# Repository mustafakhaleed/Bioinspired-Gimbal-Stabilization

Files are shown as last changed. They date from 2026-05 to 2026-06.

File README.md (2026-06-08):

# Bioinspired Stabilizing System: 3-Axis Gimbal Control

This repository hosts the research, design, and implementation of a bioinspired 3-axis gimbal stabilizing system. The project integrates mechanical design (CAD), mathematical modeling (Lagrangian dynamics), and real-time control systems.

## 🚀 Overview
The system uses three **FB5311M digital servo motors** and an **MPU6050 IMU** to maintain precise orientation despite external disturbances. 

### Key Features:
* **3-Axis Control:** Independent stabilization for Yaw, Pitch, and Roll.
* **Bioinspired Design:** Structural optimization for 3D printing and component integration.
* **Dual Control Strategy:** Comparative analysis between Linear Quadratic Regulator (LQR) and Proportional-Integral-Derivative (PID) controllers.

## 📐 Mathematical Foundation
The system dynamics are modeled using the **Euler-Lagrange** method. 

### Lagrangian Mechanics:
The Lagrangian $L$ is defined as the difference between Kinetic Energy ($K$) and Potential Energy ($P$):
$$L = K - P$$

### State-Space Model:
For small-angle approximations, the system is represented as:
$$\dot{X} = AX + BU$$
$$Y = CX + DU$$

## 🕹️ Control Implementation
A significant finding in this project was the transition from **LQR** to **PID**. 
* **LQR:** While theoretically optimal, it struggled with the specific noise and dynamics introduced by the physical placement of the IMU.
* **PID:** Provided a more robust solution. Each axis was fine-tuned ($K_p$, $K_i$, $K_d$) to eliminate steady-state error and minimize overshoot.

## 🛠️ Tools Used
* **Hardware:** Arduino Uno, MPU6050 IMU, FB5311M Servos.
* **Software:** LabVIEW (Simulation & Logic Visualization), Arduino IDE (C++), SolidWorks/CAD (Modeling).
## 📺 Demo Video
You can watch the system in action here:
[Demo Video](https://drive.google.com/drive/folders/1tQpJcSNlK2p0POUrl_nZQ9yRdT6pHToe?hl=ar)

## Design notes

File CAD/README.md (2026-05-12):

# CAD Models
This folder contains the 3D design components for the Bioinspired Stabilizing System.

### Files:
* **STL Files:** Ready for 3D printing (Recommended: PLA or PETG, 20% Infill).
* **STEP Files:** Universal CAD format for editing in SolidWorks, Fusion 360, or AutoCAD.

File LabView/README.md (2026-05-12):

# LabVIEW Simulations & GUI
This folder contains the Virtual Instruments (VIs) used for system validation.

### Included Files:
* `Bioinspired Stabilizing System Dynamic Modeling and Control... .vi`: The main interface for real-time monitoring of gimbal angles.
* `Calibration uncontrolled .vi`: A utility for calibrating the IMU to eliminate gyroscopic drift and sensor offsets.

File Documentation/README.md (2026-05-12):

Contains the full project report, mathematical derivations, and high-resolution circuit diagrams.

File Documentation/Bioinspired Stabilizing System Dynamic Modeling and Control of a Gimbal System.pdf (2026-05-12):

## Bioinspired Stabilizing System: Dynamic Modeling and Control of a Gimbal System

Hamza Saleh (120210223), Mostafa Eissa (120210241), Abdelrahman Hisham (120210254), Abdelrahman Alamrawy (120210093), Mahmoud Moustafa Mahmoud (120210362)

Supervised by Prof. Ayman Nada

Abstract—This study investigates the design, dynamic modeling, and control of a bioinspired stabilizing system, with the aim of enhancing its accuracy and stability. The system is developed using 3D modeling software and consists of three FB5311M digital servo motors for 3-axis control (with feedback). A stable base is designed to house the MPU6050 sensor, Arduino microcontroller, and a battery to power the system. By developing a mathematical model, the relationship between the servo motor movements and the system’s orientation is established. Experimental validation is conducted to assess the system’s performance in maintaining precise orientation control. The results demonstrate the effectiveness of the developed model in achieving accurate and reliable operation of the bioinspired stabilizing system.
Keywords: Bioinspired Stabilizing System, Dynamic Modeling, Arduino UNO, LabVIEW
I. INTRODUCTION

The bioinspired stabilizing system under investigation serves as a critical tool in various applications, ranging from camera stabilization to educational robotics. Accurate orientation control and stability are essential for ensuring the efficient operation of such systems. In this study, we focus on the design, dynamic modeling, and control of a 3D-printed bioinspired stabilizing system utilizing three FB5311M digital servo motors for 3-axis control.
One of the primary challenges in developing a bioinspired stabilizing system is achieving precision and responsiveness in maintaining orientation. Variations in external conditions, such as sudden movements or vibrations, can affect system performance. To address these challenges, the proposed system incorporates an MPU6050 sensor for real-time orientation measurement and uses an Arduino microcontroller to process the sensor data and control the servo motors.
The bioinspired stabilizing system is designed and 3D-printed to ensure compatibility with its components, including the MPU6050 sensor, Arduino board, and power supply (Liion batteries). A mathematical model is developed to describe the dynamics of the system, and the Arduino-based control strategy is implemented to regulate servo movements based on the yaw, pitch, and roll angles.

Experimental validation of the proposed system is conducted to evaluate its performance in maintaining stable orientation. The results demonstrate the effectiveness of the developed model and control strategy in achieving precise and reliable operation. Additionally, the project offers an accessible and educational platform for learning about dynamic modeling, control systems, and 3D printing technologies.

II. SYSTEM ANALYSIS
The bioinspired stabilizing system consists of the following components:
- FB5311M Digital Servo Motors: Three digital servo motors provide 3-axis control (yaw, pitch, and roll) for precise orientation adjustments.
- MPU6050 Sensor: A 6-axis IMU sensor used to measure angular velocity and acceleration, providing real-time orientation data.
- Arduino Uno Microcontroller: Interfaces with the MPU6050 sensor and servo motors, processing orientation data and controlling motor movements.
- CAD Model: A custom-designed CAD model ensures proper alignment and integration of all components, including the servo motors, MPU6050 sensor, Arduino Uno, and battery holder.

III. FIGURES

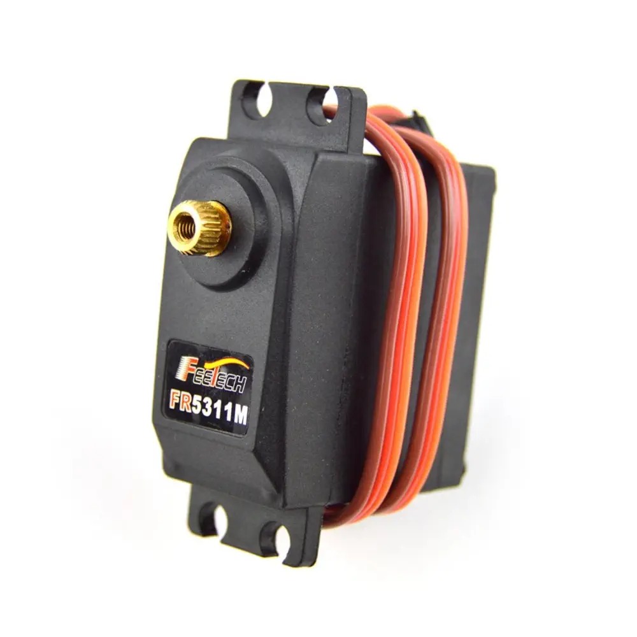
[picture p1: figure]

Fig. 1. FB5311M Digital Servo Motor

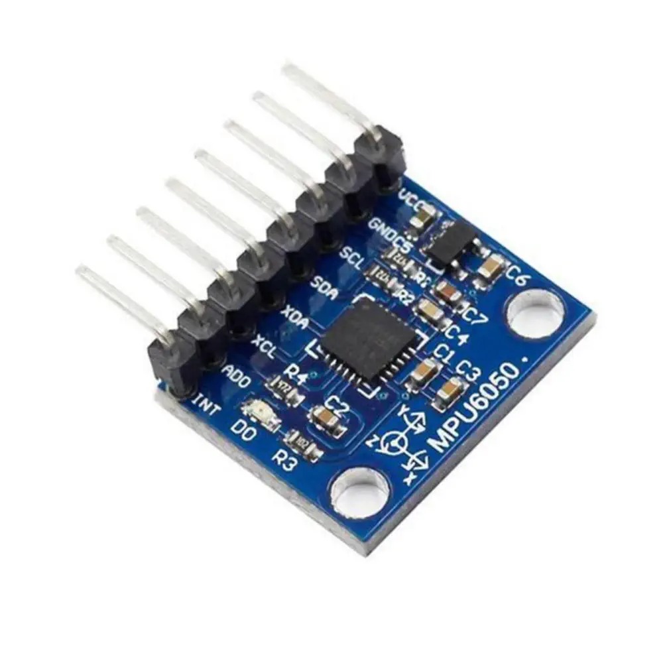
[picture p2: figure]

Fig. 2. MPU6050 IMU Sensor

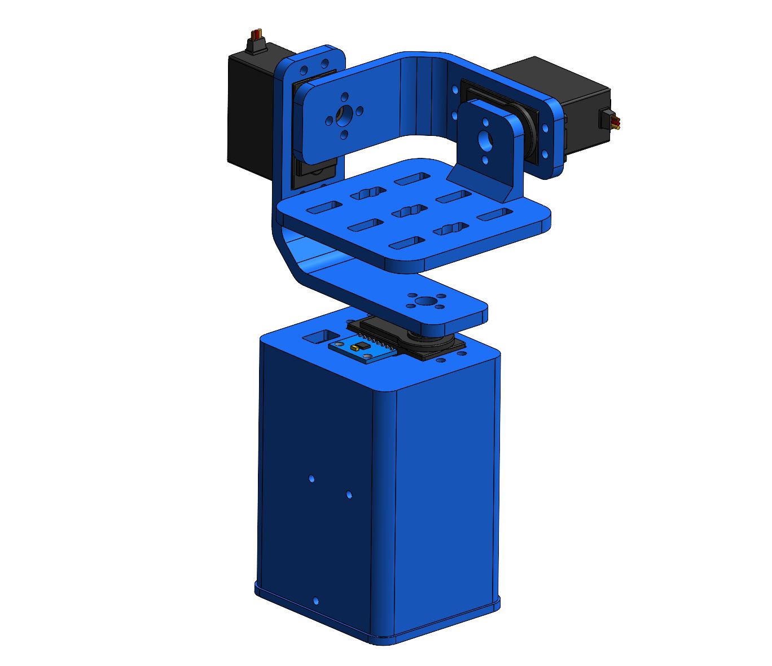
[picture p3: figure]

Fig. 3. CAD Model of the Bioinspired Stabilizing System

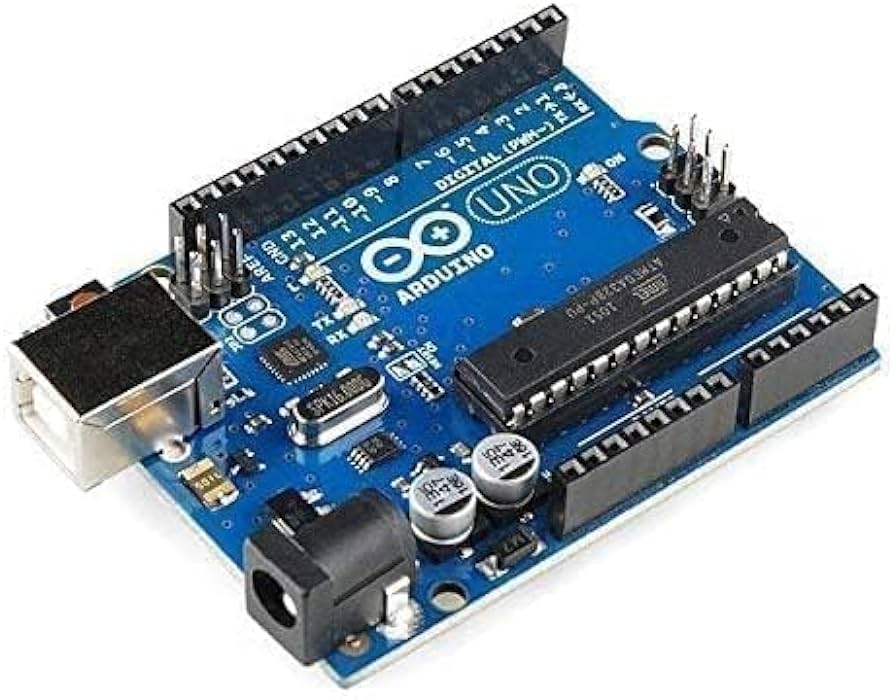
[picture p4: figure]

Fig. 4. Arduino UNO

IV. MATHEMATICAL MODEL OF THE SYSTEM
The mathematical modeling involves linearizing the system for simplicity. Assume the gimbal’s initial position is upright (θ = 0 at this position).
A. Energy-Based Modeling
Using the energy method, the Lagrangian L is defined as:

L = K − P

where: - K is the kinetic energy. - P is the potential energy. For the Bioinspired Stabilizing System: Dynamic Modeling and Control of a Gimbal System, the kinetic energy K is:

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
and the potential energy P is:

P = mgl cos θp ≈ mglθp (for small angles)

Thus, the Lagrangian becomes:

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
r − mglθp
B. Euler-Lagrange Equations
The Euler-Lagrange equations are:

d

dt
∂L
∂ ˙θi
−

∂L
∂θi

= τi

where τi

is the torque applied to the i-th axis (i = p, y, r). For the pitch axis (θp):

jp

¨θp + mglθp = τp

For the yaw axis (θy):

jy

¨θy = τy

For the roll axis (θr):

jr

¨θr = τr

C. Linearization
The equations are already linearized using small-angle approximations (sin θ ≈ θ, cos θ ≈ 1).
D. State-Space Representation
The state-space representation of the Bioinspired Stabilizing System: Dynamic Modeling and Control of a Gimbal System is derived as follows:

X˙ = AX + BU

Y = CX + DU

where: - X is the state vector. - U is the input vector. - Y is the output vector.
The state vector X is defined as:

X =

θp
˙θp
θy
˙θy
θr
˙θr

The input vector U is defined as:

U =

τp
τy
τr

The state-space matrices are:

A =

0 1 0 0 0 0
−
mgl jp | 0 0 0 0 0
0 | 0 0 1 0 0
0 | 0 0 0 0 0
0 | 0 0 0 0 1
0 | 0 0 0 0 0

B =

0 | 0 | 0
1 jp | 0 | 0
0 | 0 | 0
0 | 1 jy | 0
0 | 0 | 0
0 | 0 | 1 jr

C =

1 0 0 0 0 0
0 0 1 0 0 0
0 0 0 0 1 0

D =

0 0 0
0 0 0
0 0 0
E. Combined State-Space Equations

The state-space equations are:

X˙ =

0 1 0 0 0 0
−

mgl
jp

0 0 0 0 0
0 | 0 0 1 0 0
0 | 0 0 0 0 0
0 | 0 0 0 0 1
0 | 0 0 0 0 0

X +

0 | 0 | 0
1 jp | 0 | 0
0 | 0 | 0
0 | 1 jy | 0
0 | 0 | 0
0 | 0 | 1 jr

U

Y =

1 0 0 0 0 0
0 0 1 0 0 0
0 0 0 0 1 0
- X +

0 0 0
0 0 0
0 0 0
U
F. Interpretation
- The matrix A describes the system dynamics, including the restoring torque due to gravity for the pitch axis. - The matrix B maps the input torques to the system states. - The matrix C selects the angular positions as outputs. - The matrix D is zero because there is no direct feedthrough from inputs to outputs.
V. DESIGN RATIONALE

The design of the Bioinspired Stabilizing System focuses on achieving precise and stable control while ensuring safety and robustness. The system utilizes a feedback control loop to continuously monitor and adjust the orientation of the gimbal.

A. Key Elements in the Design
- Feedback Loop: Maintains the system’s orientation at the desired setpoint by continuously comparing the actual orientation (measured by sensors) with the desired orientation.
- Decoupled Control: Each axis (pitch, yaw, and roll) is controlled independently, simplifying the control design and implementation.
- Safety Mechanisms: Includes limits on angular velocities and positions to prevent mechanical damage, as well as fault detection for sensor or motor failures.
B. Control System Architecture
The control system architecture consists of the following components:
- Sensors: Measure the angular position and velocity of each axis (IMUs).
- Actuators: Apply torques to each axis using motors (servo motors).
- Controller: Computes the optimal control inputs using the LQR algorithm and sends commands to the actuators.
- Setpoint: The desired orientation is provided by the user or an external system (e.g., a camera stabilization system).
This design ensures precise and stable control of the Bioinspired Stabilizing System: Dynamic Modeling and Control of a Gimbal System, making it suitable for applications such as camera stabilization, drone navigation, and robotic systems.

VI. SIMULATION INSIGHTS
The simulation in LabVIEW ensures proper functionality before practical implementation. Key components in the Lab-VIEW block diagram include:
A. Serial Communication and Servo Initialization

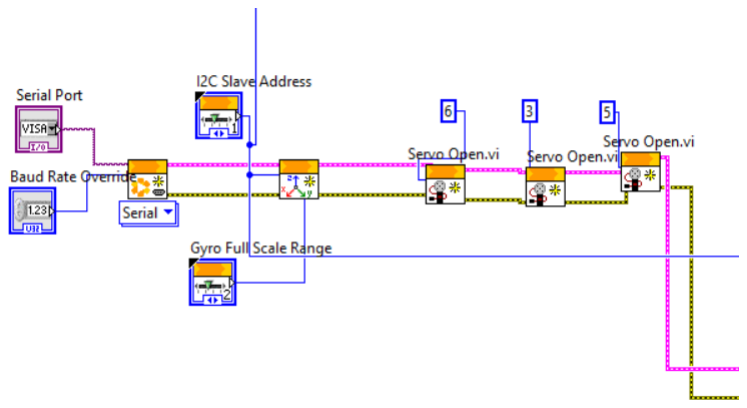
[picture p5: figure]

Fig. 5. Serial Communication and Servo Initialization

The blocks configure serial communication, set up the I2C slave address, and initialize servos for motor control.

B. IMU Calibration and Control Signal Processing

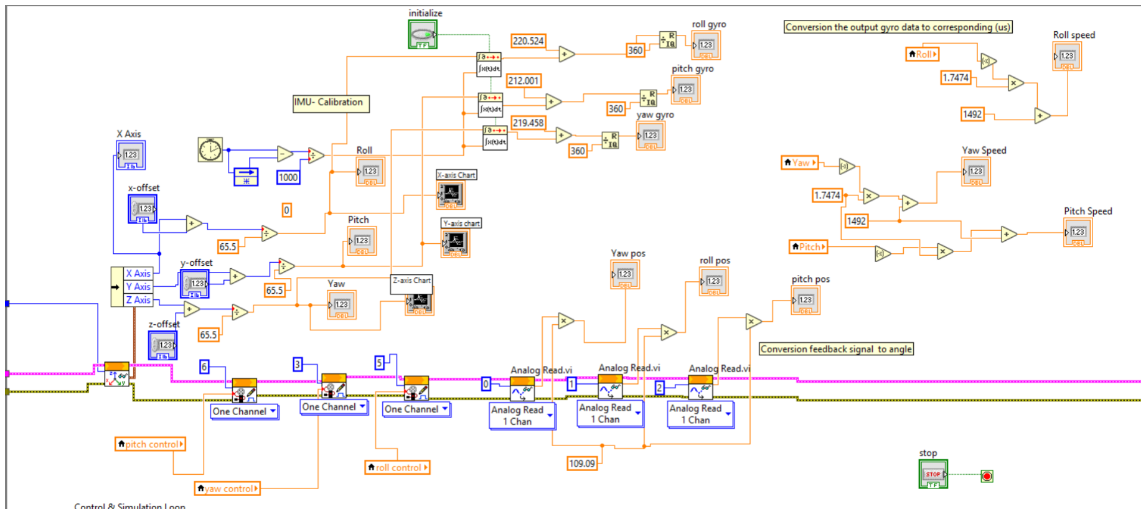
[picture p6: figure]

Fig. 6. IMU Calibration and Control Signal Processing

This section visualizes the calibration of the IMU (Inertial Measurement Unit), including offset adjustments for the X, Y, and Z axes. It processes gyroscopic data to determine roll, pitch, and yaw angles and their respective speeds. The outputs are integrated into control signals for the system’s stabilization and feedback mechanisms.

C. Roll Control PID Implementation

Fig. 7. Roll Control PID Implementation

This section demonstrates the PID control logic for stabilizing the roll axis. It calculates the error between the desired and actual roll positions and processes it through proportional, integral, and derivative components. The resulting control signal is adjusted for system dynamics using gain values and a saturation block, ensuring smooth and stable roll control.

D. Yaw Control PID Implementation

Fig. 8. Yaw Control PID Implementation

This section visualizes the PID control structure for managing the yaw axis. It calculates the yaw error based on the difference between the desired and actual yaw positions. The error is processed through proportional, integral, and derivative terms, which are scaled by respective gain values. The combined control signal is regulated using a saturation block to ensure stability and precision in yaw axis control.

E. Pitch Control PID Implementation

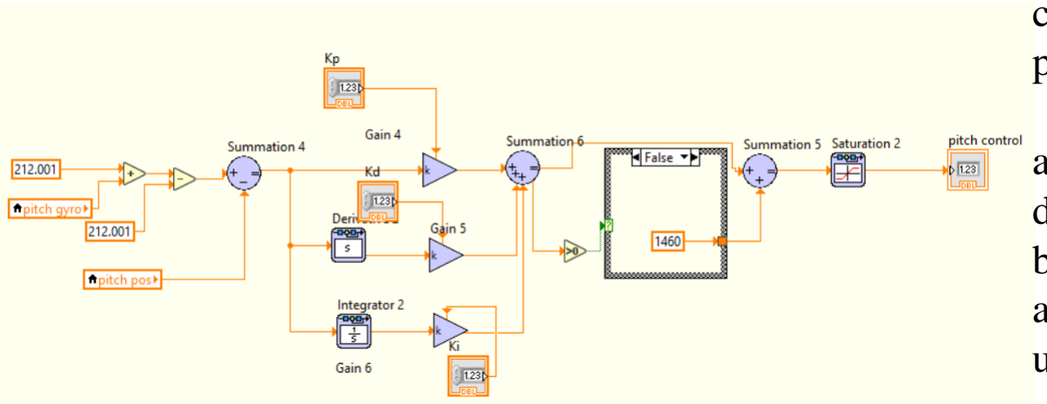
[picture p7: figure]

Fig. 9. Pitch Control PID Implementation

This section visualizes the PID control structure for managing the pitch axis. It calculates the pitch error based on the difference between the desired and actual pitch positions. The error is processed through proportional, integral, and derivative terms, each scaled by respective gain values (Kp, Ki, Kd). The combined control signal is regulated using a saturation block to ensure stability and precision in pitch axis control.

F. State-Space Controller Design with LQR Optimization

Fig. 10. State-Space Controller Design with LQR Optimization

Diagram implements a state-space representation and Linear Quadratic Regulator (LQR) optimization to design a control system. The inputs A, B, and C define the state-space matrices, while controllability is verified using the controllability matrix and rank calculation. The system’s poles and zeros are analyzed, and the LQR block computes optimal feedback gain
(K) based on weighting matrices Q and R, which are then divided into components for yaw, pitch, and roll control gains.

VII. RESULTS

Initially, the control system for the Bioinspired Stabilizing System was designed using a Linear Quadratic Regulator (LQR). The LQR was chosen for its optimal control strategy, which minimizes a cost function balancing performance and control effort. The initial implementation of LQR used the full state vector, including angular positions and velocities, to compute the control inputs. Despite its theoretical advantages, practical challenges arose during testing.
It was observed that the placement of the MPU6050 sensor at the final position on the gimbal introduced additional dynamics and disturbances that were not effectively handled by the LQR. This sensor placement required a more responsive and adaptable control strategy to maintain precise orientation under varying conditions.
To address these challenges, the controller was redesigned using a Proportional-Integral-Derivative (PID) control strategy. The PID controller was tuned to optimize the system’s performance by adjusting its proportional (Kp), integral (Ki), and derivative (Kd) gains. Fine-tuning was performed iteratively based on experimental feedback to achieve the best possible stability and responsiveness.
The following steps were undertaken during the transition:
- Controller Redesign: The LQR was replaced with a PID controller to account for the real-time dynamics and disturbances caused by the placement of the IMU.
- Fine-Tuning of Gains: The PID gains (Kp, Ki

, Kd) were
adjusted iteratively through trial and error to minimize overshoot, settle time, and steady-state error.
- Validation: The redesigned system was tested extensively, demonstrating significant improvements in maintaining orientation and stability under varying conditions. The PID controller’s ability to adapt to the system’s dynamics and its straightforward implementation made it a practical choice for real-world applications. Experimental results confirmed that the PID controller provided reliable and precise stabilization, effectively addressing the limitations encountered with the LQR.
A. Key Findings
- Performance Comparison: The LQR struggled to handle the additional dynamics introduced by the IMU’s placement. In contrast, the PID controller proved more effective in achieving stable and precise orientation control.
- Tuning Sensitivity: The system’s performance was highly sensitive to the PID parameters, underscoring the importance of fine-tuning for optimal results.
- Robustness: The PID controller demonstrated robustness in handling disturbances and varying conditions, outperforming the LQR in practical scenarios.
This transition highlights the importance of selecting an appropriate control strategy based on the system’s physical configuration and real-world requirements. Future work could focus on automating the PID tuning process or exploring adaptive PID controllers to further enhance performance.

VIII. APPLICATIONS AND FUTURE IMPROVEMENTS

A. Applications

The Bioinspired Stabilizing System developed in this project has wide-ranging applications across various fields. Key applications include:
- Camera Stabilization: The system enhances stability in cameras and drones, compensating for unwanted movements and vibrations. This ensures smooth, high-quality video recording in dynamic environments.
- Robotics: It can be employed in robotic arms or platforms to improve precision and control during tasks like assembly, inspection, and manipulation in both educational and industrial contexts.
- Virtual Reality (VR) and Augmented Reality (AR): By stabilizing the user’s view, the system reduces motion sickness and enhances the immersive experience in VR/AR applications.
- Medical Devices: The system ensures stability and precision in medical equipment, such as surgical robots and handheld diagnostic tools, enabling safe and accurate operation during critical procedures.
- Aerospace: It stabilizes sensors, cameras, or communication devices on satellites, drones, and aircraft, ensuring reliable data collection and transmission in challenging conditions.
B. Future Improvements
The current system demonstrates effectiveness and robustness, but there are several avenues for further enhancement:
- Integration of Advanced Sensors: Incorporating sensors such as gyroscopes, accelerometers, and magnetometers can improve real-time detection and compensation for complex movements.
- Machine Learning Algorithms: Adding machine learning capabilities can make the system more adaptable and predictive, enabling it to learn from past disturbances and respond proactively to new ones.
- Wireless Communication: Utilizing wireless technologies like Wi-Fi or Bluetooth allows remote monitoring and control, facilitating integration into IoT (Internet of Things) platforms.
- Energy Efficiency: Optimizing power consumption with low-power microcontrollers and energy-efficient components can make the system more suitable for portable or solar-powered applications.
- Modular Design: A modular and scalable design enables adaptation to different sizes, configurations, and applications, broadening the system’s usability.
- Enhanced Control Algorithms: Implementing advanced control strategies such as adaptive control can further improve precision, stability, and responsiveness.

IX. CONCLUSION
This study successfully presents the dynamic modeling and control of a Bioinspired Stabilizing System using servo motors and an MPU6050 sensor. By developing a comprehensive mathematical model and implementing a robust feedback control loop, the system achieves accurate and stable orientation control.
Experimental validation using Arduino UNO and LabVIEW confirms the system’s effectiveness and the reliability of the control strategy. This implementation demonstrates potential applications in diverse fields, ensuring precision and efficiency in stabilization tasks. Future work will focus on integrating advanced sensors, improving energy efficiency, and leveraging machine learning-based control strategies to further enhance system performance and adaptability.

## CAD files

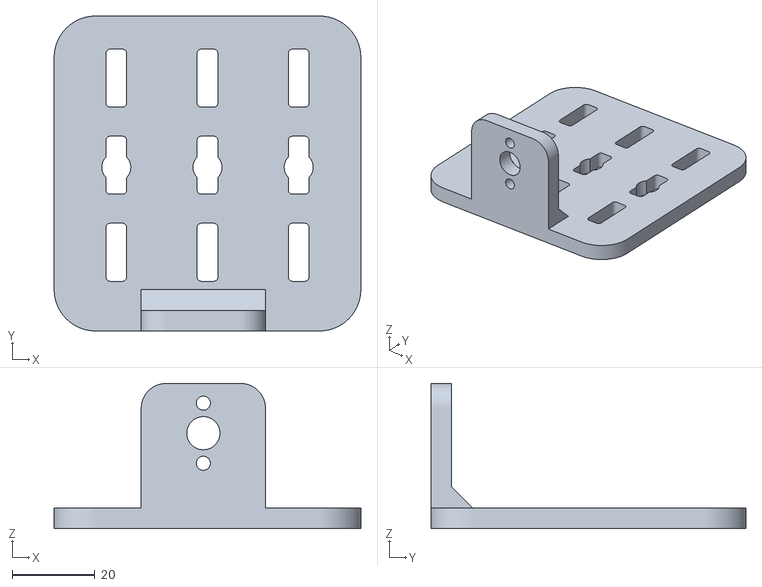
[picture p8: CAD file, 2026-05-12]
CAD/Top platform.STL
74.0 x 76.0 x 35.0

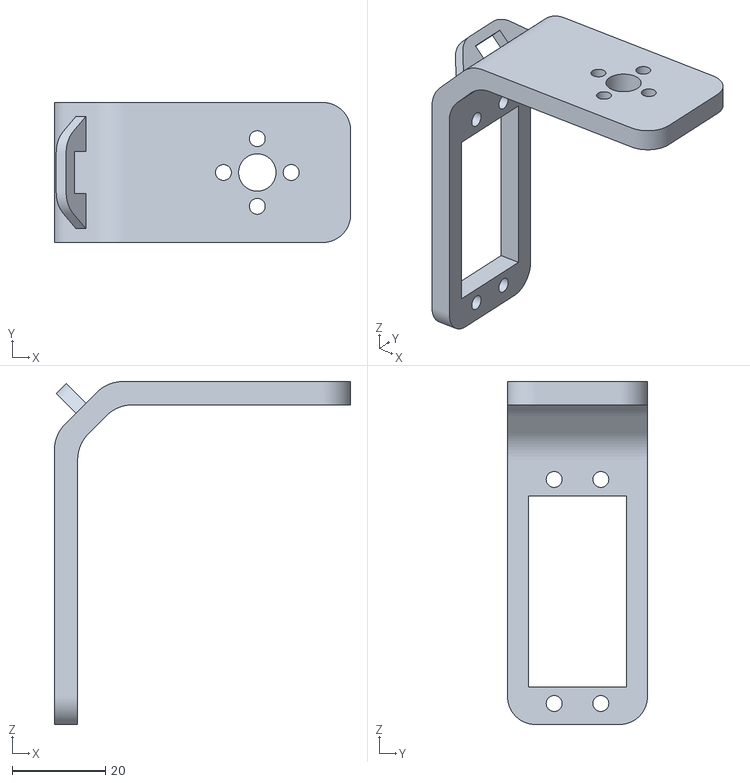
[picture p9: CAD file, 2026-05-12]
CAD/Base 03 - Pitch servo.STL
63.5 x 30.0 x 73.5

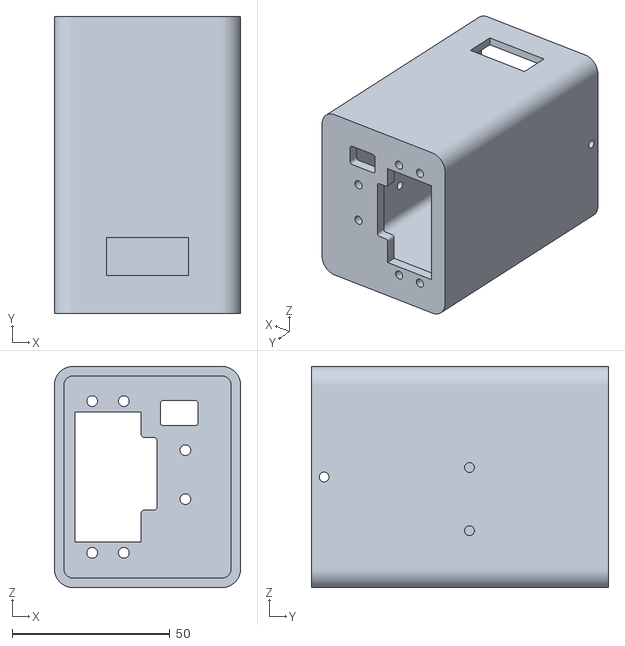
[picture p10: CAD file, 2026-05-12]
CAD/Base 01 - Yaw servo.STL
59.0 x 94.0 x 70.0

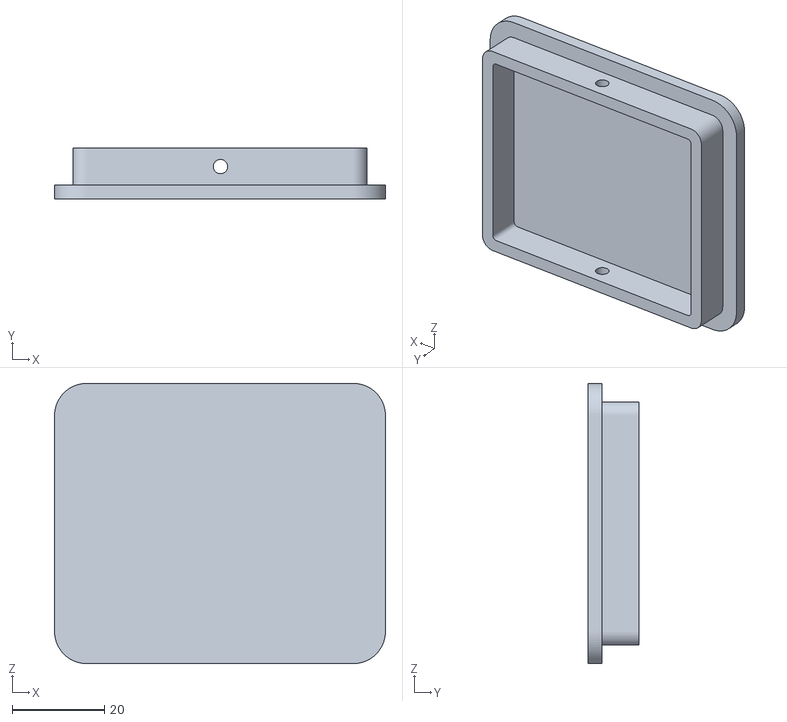
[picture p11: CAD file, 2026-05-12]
CAD/bottom cover.STL
71.8 x 11.0 x 60.8

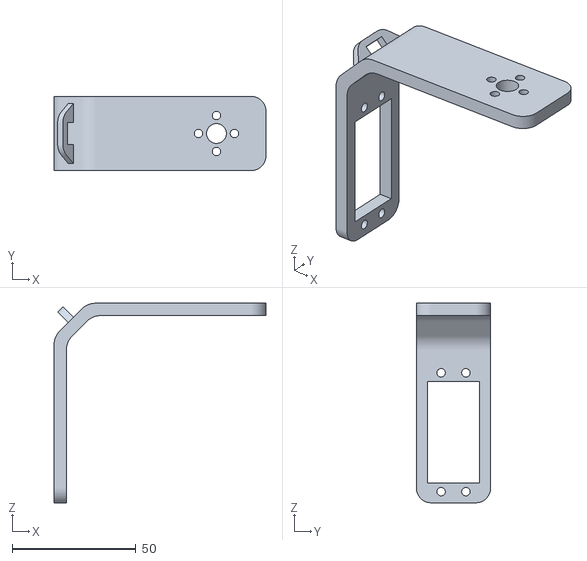
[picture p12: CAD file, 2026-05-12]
CAD/Base 02 - Roll servo.STL
85.6 x 30.0 x 80.6

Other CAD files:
CAD/control project.3mf

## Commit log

2026-05-12 Create CAD
2026-05-12 Update README with project report details
    Add project report and circuit diagrams information.
2026-05-12 Add CAD models section to README
